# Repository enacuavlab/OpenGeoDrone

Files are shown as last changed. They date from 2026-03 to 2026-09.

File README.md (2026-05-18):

# OpenGeoDrone — Parametric RC VTOL Generator

> A fully parametric VTOL designed in OpenSCAD, built for **vase mode 3D printing**. The project generates a complete aircraft: wings with internal structure, a Bézier-profiled fuselage, motor arms, winglets, ailerons, and a center body.

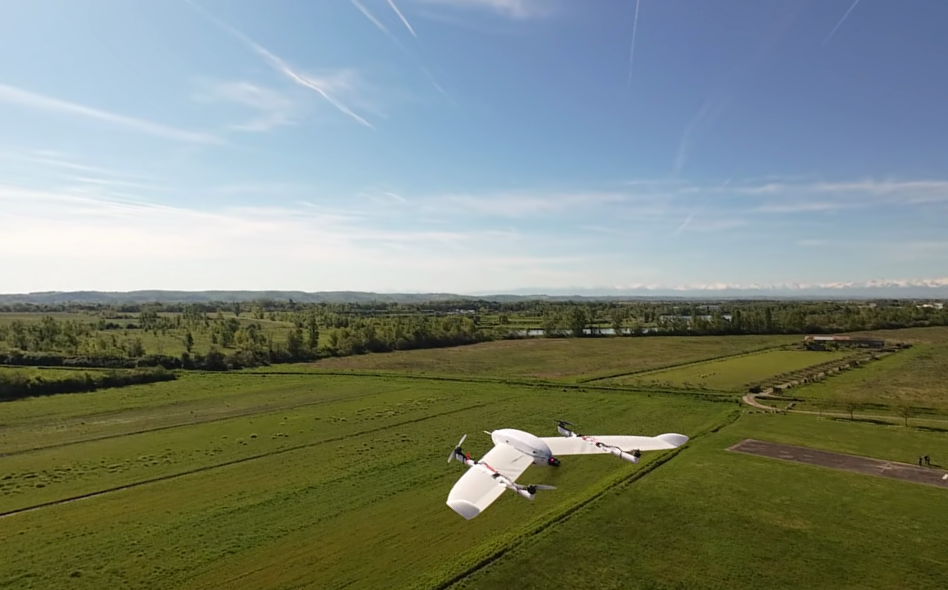
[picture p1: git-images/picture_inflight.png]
OpenGeoDrone_inflight


---

## Financial Support

The development of the OpenGeoDrone was funded by the French National Research Agency (ANR, Agence Nationale de la Recherche) and the German Research Foundation (DFG, Deutsche Forschungsgemeinschaft) within the framework of the Franco-German research project FlyHigh (ANR FlyHigh ANR-24-CE92-0015  and GR 5407/2-1)

Logo_German_Research_Foundation 
ANR

---

## Table of Contents

- [Overview](#overview)
- [Repository Structure](#repository-structure)
- [Print Tutorial](#print-tutorial)
- [OpenSCAD Quick Start](#openscad-quick-start)
- [How the Wings Are Built — The Vase Mode Method](#how-the-wings-are-built--the-vase-mode-method)
- [How the Fuselage Is Built — C1 Quintic Bézier](#how-the-fuselage-is-built--c1-quintic-bézier)
- [Parts to Print](#parts-to-print)
- [Key Parameters Reference](#key-parameters-reference)
- [Slicer Setup](#slicer-setup)
- [Performance Tips](#performance-tips)
- [Credits and Prior Work](#credits-and-prior-work)
- [License](#license)

---

## Overview

OpenGeoDrone is a VTOL UAV designed entirely in OpenSCAD. The goal is to produce aerodynamically efficient, lightweight, and printable parts using the **spiral vase mode** of FDM slicers (also called "spiralize outer contour"). This mode prints the outer skin as a single continuous spiral — no retractions, no seams, very low weight.

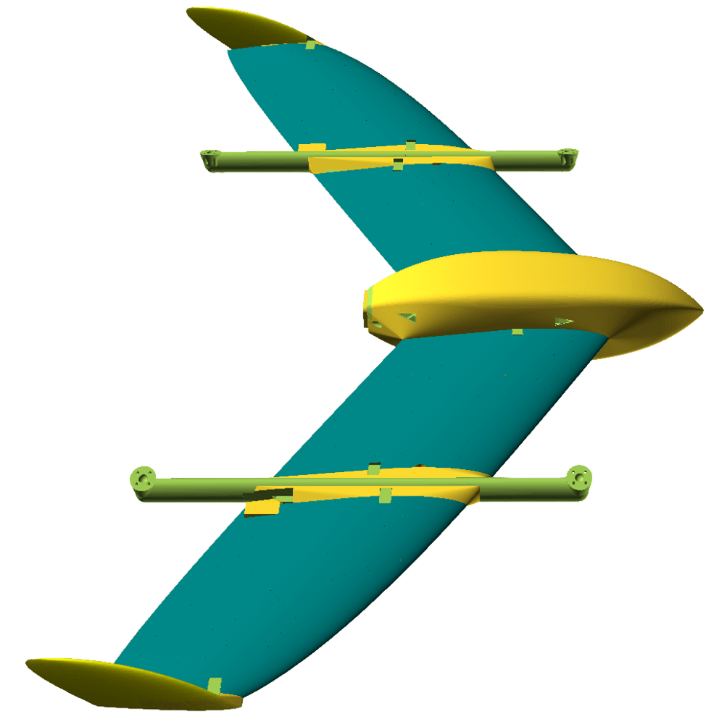
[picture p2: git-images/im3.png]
OpenGeoDrone


The aircraft is parametric end-to-end: wing span, chord, sweep, airfoil, motor position, spar count, aileron geometry, fuselage shape, and more are all driven by variables in a single file (`OpenGeoDrone.scad`). Changing one number regenerates every dependent part automatically.

**VTOL, Vertical Take-Off and Landing :**

The aircraft takes off and lands using its four hovering motors. It flies like a plane thanks to a pusher motor and two elevons.

OpenGeoDrone_inflight OpenGeoDrone_inflight

**Default aircraft specs (all configurable):**

| Specification | Value | 
|---|---|
| **Half-wingspan** | 510 mm (total ~1200 mm + center body) | 
| **Mass without battery** | 1.066kg |
| **Max payload mass** | 1.15kg with 60% throttle in hovering |
| **Flight endurance** | 25min in plane mode with 90s Hovering with 4S 4Ah battery |
| **Min plane flying speed** | 14m/s |
| **Hoovering** | 34% throttle |
| **Root chord** | 210 mm |
| **Airfoil ** | MH61 (cambered, suitable for slow stable RC flight) |
| **carbon fiber spars** | 5 (2 per half-wing + 1) |
| **Motors** | 4 hovering motors on tilted arms + one rear pusher |
| **Elevons** | 2 for pitch and roll control |
| **Center part dimensions** | 275mmx90mm  |
| **Wings easy to remove** | no cables |
| **Inertial Matrix** | coming soon |
| **Hovering power with 4S** | 400W |
| **Plane power with 4S** | 90W |

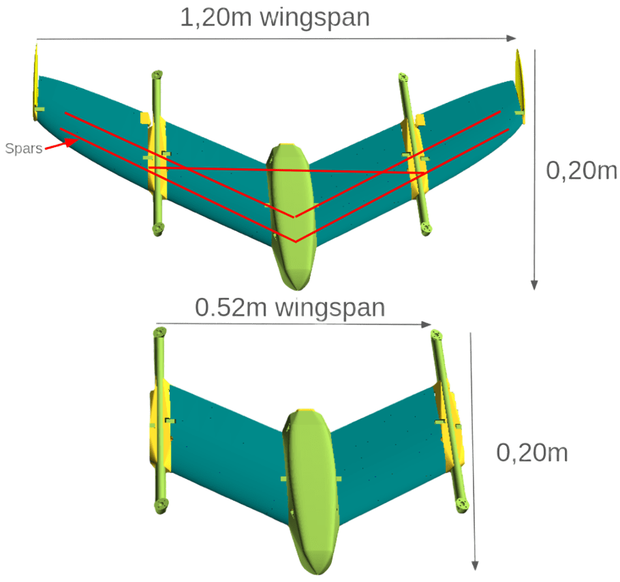
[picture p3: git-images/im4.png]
Parameters Overview


**Differents parts:**

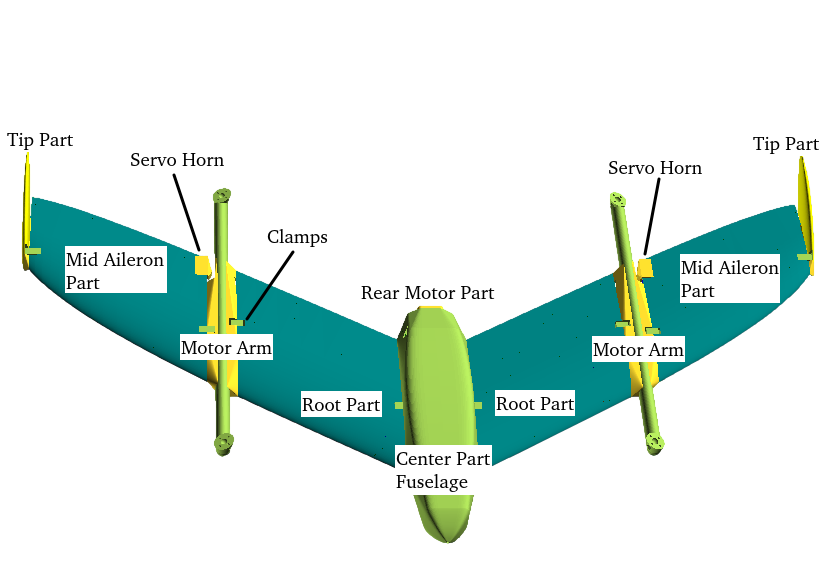
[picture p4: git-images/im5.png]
Parts Overview


---

## Print Tutorial

Every parts of the plane are printable. STL files are accessible in `stl_print_part` directory and the bambulab preset for X1C and H2D are available in `bambulab_preset` directory. It is also possible to print directly the project with the 3mf format in the `3mf_print_part` directory.

Use a **0.4mm nozzle** for all prints.

### 1st Method : 3mf format print method

It will load automatically the Bambulab preset on H2D or X1C.You can find this files in the folder `3mf_print_part`

**For X1C or H2D** : 

Use PLA Aero for :

- X1C_Left_Root_part
- X1C_Left_Mid_Aileron_part
- X1C_Right_Root_part
- X1C_Right_Mid_Aileron_part

Use PETG Basic for :

- X1C_Motor_Arms_and_sides
- X1C_Fuselage_and_Clamps
- X1C_Center_part

You choose of course the part corresponding to your printer.

### 2nd Method : STL format print method

For PLA Aero Wings, use the `0.20mm_Standard-PLA_Aero_VaseMode_XXX.json` upon your printer and print the following parts.

**PLA Aero Wings** :

- Left_Root_part
- Right_Root_part
- Left_Mid_Aileron_part
- Right_Mid_Aileron_part

For Side parts, Clamps parts and Center body below, you can print it in PETG Basic in standard mode (0.20mm Standard)

**Side parts** :

- Left_Motor_arm_back
- Left_Motor_arm_front
- Right_Motor_arm_back
- Right_Motor_arm_front
- Left_Servo_horn
- Right_Servo_horn

**Clamps parts** :

- 6 x Clamp_fixation_big

**Center body** :

- Center_part
- Fuselage_bottom_back_part
- Fuselage_front_part
- Fuselage_upper_part
- Rear_motor_part

### Hardware (not printed)

- Carbon fiber tube ⌀5.5 mm
- Carbon fiber tube ⌀6.5 mm
- Flight controller (e.g. Tawaki)
- 2 Servo
- RC
- Pitot tube
- GPS module and Modem to Ground station if needed
- 4 Motors for hoovering (F40) 
- 1 ESC 4 to 1 
- 2 Propellers 7x4 and 2 reverse Propellers 7x4  
- 1 Motor for pusher (low kV < 1200) 
- 1 ESC for pusher 
- 1 Propeller 9x6

### Assembly order

1. **TODO**

---

## Repository Structure

```
Vase_wing_openscad/
│
├── OpenGeoDrone.scad               # Main entry point — all parameters and top-level assembly
│
├── lib/
│   ├── Wing-Creator.scad      # Wing shell geometry (airfoil lofting, sweep, washout)
│   ├── Grid-Structure.scad    # Internal rib and spar grid structure
│   ├── Grid-Void-Creator.scad # Clearance voids ensuring vase mode continuity
│   ├── Rib-Void-Creator.scad  # Optional weight-reduction holes in ribs
│   ├── Spar-Hole.scad         # Carbon spar tube holes and retaining rings
│   ├── Aileron-Creator.scad   # Aileron geometry, pin holes, command pin voids
│   ├── Motor-arm.scad         # Motor arm tube, tilt, attachment to wing
│   ├── Winglet-Creator.scad   # Winglet geometry and attachment interface
│   ├── Center-part.scad       # Center body / fuselage assembly
│   ├── Servo-Hole.scad        # Servo pocket geometry
│   ├── Helpers.scad           # Utility functions (chord interpolation, spline, etc.)
│   ├── Tools.scad             # General geometry helpers
│   └── openscad-airfoil/      # Airfoil coordinate libraries (MH45, NACA0008, etc.)
│
├── bambulab_preset/           # Ready-to-import slicer presets for Bambu Lab printers
├── git-images/                # Screenshots of rendered wings for this README
├── stl_generator.sh           # Bash script to batch-export all STL files via OpenSCAD CLI
└── README.md                  # This file
```

**The single file to open is `OpenGeoDrone.scad`.** All parameters live at the top of that file. The `lib/` modules are included automatically — you never need to edit them directly.

---

## OpenSCAD Quick Start

### 1. Install OpenSCAD with the Manifold engine

Standard OpenSCAD is very slow on this model. Use the **development snapshot** with the Manifold geometry engine, which is approximately 100× faster:

1. Download a development snapshot: [openscad.org/downloads.html#snapshots](https://openscad.org/downloads.html#snapshots)
2. Open **Edit → Preferences → Features**
3. Enable the **Manifold** checkbox

### 2. Open the project

```
File → Open → OpenGeoDrone.scad
```

### 3. Select the part to render

At the top of `OpenGeoDrone.scad`, set exactly one part flag to `true`:

```openscad
// --- Choose the part to export ---
Root_part                 = true;   // Wing root section (fuselage side)
Mid_Aileron_part          = false;  // Mid section + aileron as one piece
Tip_part                  = false;  // Wing tip section (+ winglet if enabled)
Motor_arm_full            = false;  // Motor arm (front + back together)
Motor_arm_front           = false;  // Front half of motor arm only
Motor_arm_back            = false;  // Rear half of motor arm only
Servo_horn                = false;  // Servo horn

Center_part               = false;  // Center body / fuselage
Rear_motor_part           = false;  //Part for Rear motor attach
Clamp_fixation_big        = false;  // Clamp to fix parts together (ie wings to center_part or motor_arm)
Clamp_fixation_small      = false;  // Clamp to fix parts together (ie wing_tips to center_part or motor_arm)
Fuselage_front_part       = false; // Fuselage
Fuselage_bottom_back_part = false; // Fuselage
Fuselage_upper_part       = false; // Fuselage
Full_fuselage             = false; // Fuselage parts all together

Full_system        = false;  // Full assembly preview (not for printing)

// --- Choose the side ---
Left_side  = true;   // Generate left wing half
Right_side = false;  // Generate right wing half (mirrored)
```

### 4. Render and export

Press **F6** to render, then **File → Export → Export as STL**.

To export as STL all parts at once, use the batch script:

```bash
./stl_generator.sh
```

Parts will be exported in folder **stl_output**

---

## How the Wings Are Built — The Vase Mode Method

### What is vase mode?

Vase mode (also called "spiralize outer contour") is a slicer setting that prints only the outer wall as a single continuous upward spiral — no infill, no top/bottom layers, no retractions. For a wing this is ideal: the airfoil skin becomes a single-layer seamless tube that is light, smooth, and aerodynamically clean.

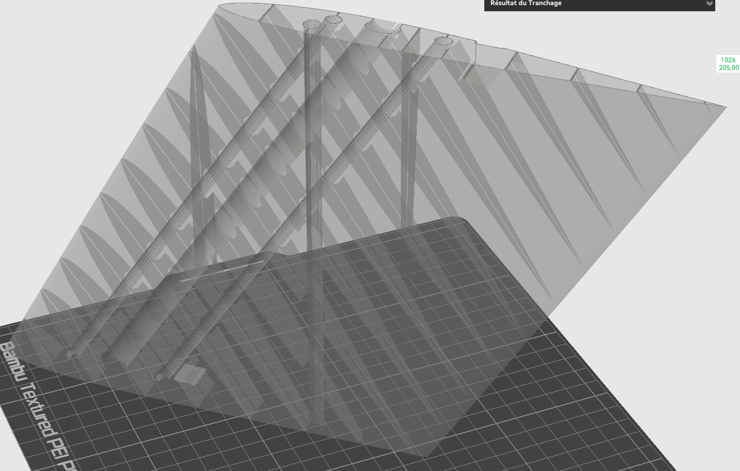
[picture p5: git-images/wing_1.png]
Print Wing


The geometry must be designed specifically for this mode. At every layer height, the cross-section of the model must form a **single closed contour** — if the slicer sees multiple disconnected loops, it cannot maintain the spiral and the print fails. Every design decision in this project (grid voids, spar hole placement, aileron connection geometry) exists to satisfy this constraint.

Print Wing

### Step 1 — Airfoil cross-sections

The wing shape starts with a 2D airfoil polygon. OpenGeoDrone uses profiles from the [openscad-airfoil](https://github.com/guillaumef/openscad-airfoil) library, which stores airfoil coordinates as OpenSCAD path arrays. These were pre-processed from UIUC `.dat` files using AeroSandbox to increase point density, resulting in smoother printed curves.

The default airfoil is **MH61**, a cambered profile well-suited for slow stable RC flight. The winglet uses **NACA0008**, a symmetric thin profile. Up to three different airfoils can be blended along the span (root, mid, tip) using `slice_transitions`.

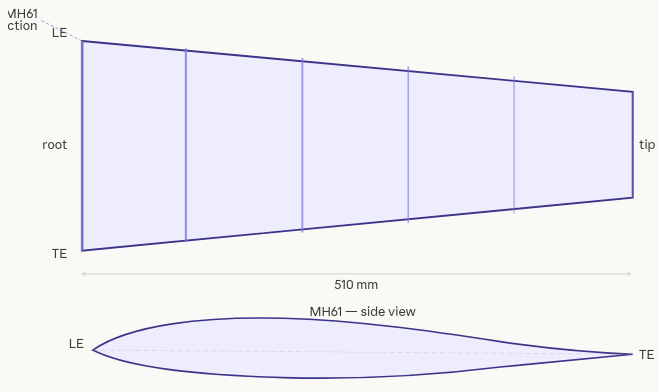
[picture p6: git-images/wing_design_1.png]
Create profile and rescale


### Step 2 — Wing shell lofting

The wing outer skin is generated by `CreateWing()` in `Wing-Creator.scad`. The airfoil cross-section is placed and transformed at `wing_sections` spanwise stations (default: 50). At each station `z`, the section is:

- **Scaled** to the local chord length, following either a trapezoidal or elliptic planform (`wing_mode` parameter)
- **Swept** in X by a user-defined spline (`lead_edge_sweep` parameter) — this shifts the leading edge rearward as span increases, giving the wing its arrow shape
- **Curved** in Y by an optional spline (`lead_edge_curve_y`) — used for dihedral
- **Washed out** by rotating the section about a pivot point (`washout_pivot_perc` parameter) to progressively reduce angle of attack toward the tip, which improves stall behavior

The elliptic chord distribution uses a super-ellipse formula:

```
chord(z) = root_chord × (1 − (z / span)^p)^(1/p)
```

where `p = elliptic_param`. 

- A value of 2 gives a true ellipse 
- Values > 2 give a squarer tip 
- Values < 2 give a sharper tip

Apply transformation Elliptic wing, sweep, curve, washout, etc …

Each station is a near-zero-thickness extruded polygon. OpenSCAD's `hull()` operation connects consecutive stations into a smooth lofted surface — the wing outer skin.

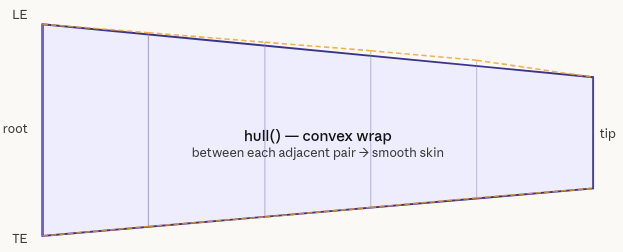
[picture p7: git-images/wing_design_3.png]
Connect all section together


### Step 3 — Internal grid structure

The wing skin alone is too flexible. An internal rib-and-spar grid is built by `Grid-Structure.scad` and subtracted from the wing volume, creating a periodic internal skeleton visible through the skin after printing.

Two grid modes are available:

**Mode 1 — Diamond grid:** A diagonal lattice scaled by `grid_size_factor`. Lightweight and uniform, but without defined spar paths.

**Mode 2 — Spar + cross-rib grid (default):** Longitudinal spar walls at the same chord percentages as the carbon tubes, connected by `rib_num` transverse ribs. This is a structurally coherent option — the grid walls and the tube channels form a unified load path.

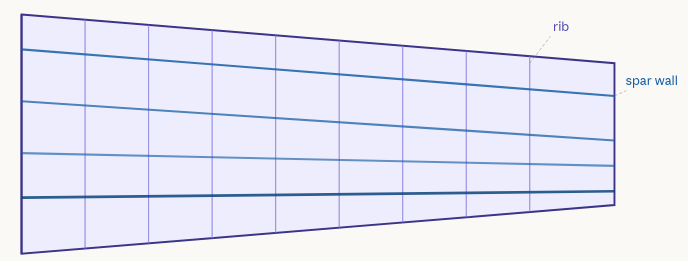
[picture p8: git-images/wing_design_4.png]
Internal grid structure and spars


After the grid is built, `CreateGridVoid()` cuts narrow channels along every grid wall. **This is the key to vase mode compatibility**: the channels reduce each internal wall to a thin fin rather than a solid block, ensuring the slicer always sees a single outermost contour at every layer.

Keypoints cuts narrow channels along every grid wall

### Step 4 — Carbon spar holes

Three carbon fiber tube channels are cut through the wing by `Spar-Hole.scad`:

| Spar | Position from leading edge | Tube diameter |
|---|---|---|
| Spar 1 | 15% of chord | 5.5 mm |
| Spar 2 | 37% of chord | 5.5 mm |
| Spar 3 | 75% of chord | 6.5 mm |

Spar 1 and 2 holes are angled to follow the leading edge sweep, so the carbon tube runs geometrically parallel to the wing planform. Spar 3 is perpendicular to the root face and bigger diameter to increase the structure rigidity and create a block mechanism with a triangle system.

Around each hole, a ring of 12 small retaining circles (`spar_circle_holder = 0.25 mm`) creates a snap-fit friction interface that holds the tube in place after insertion without glue.

The same holes continue into the center body to connect both wing halves through the fuselage.

OpenSCAD prints the required tube lengths to the console at render time:

```
[SPAR] Spar 1 at 15% from LE is XXX mm length.
[SPAR] Spar 2 at 37% from LE is XXX mm length.
[SPAR] Spar 3 at 75% from LE is XXX mm length.
```

**Cut your carbon tubes to these exact lengths before assembly.**

### Step 5 — Elevons

Elevons are sticked to the mid part :
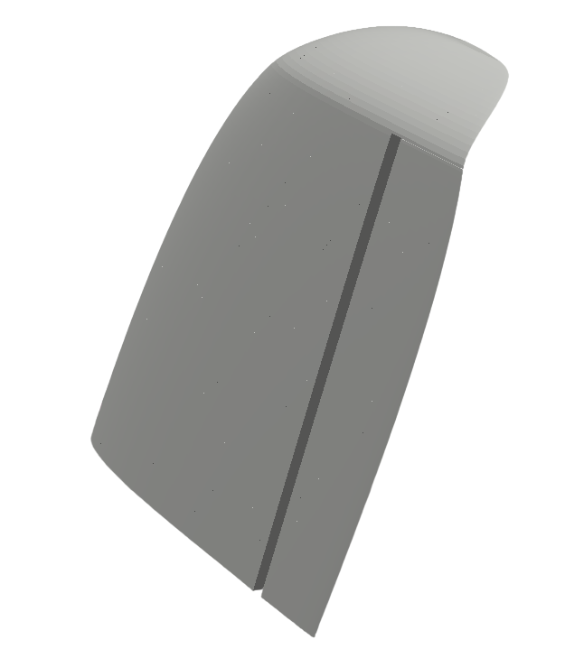
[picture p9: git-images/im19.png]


The connection between the mid part and the aileron is performed by a thin layer and tht actuation is done by the servo horn part connected to your servo:

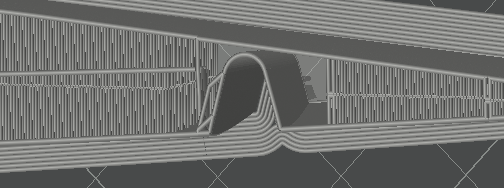
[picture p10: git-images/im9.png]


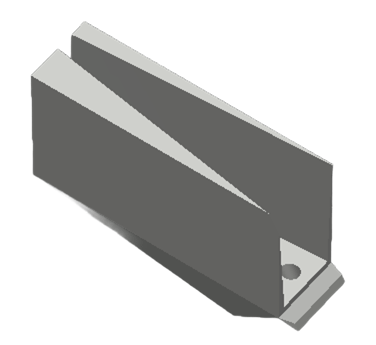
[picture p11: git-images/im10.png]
Servo Horn Part


### Step 6 — Clamp

Clamp are used to hold parts together, insert them slowly into the 6 places :

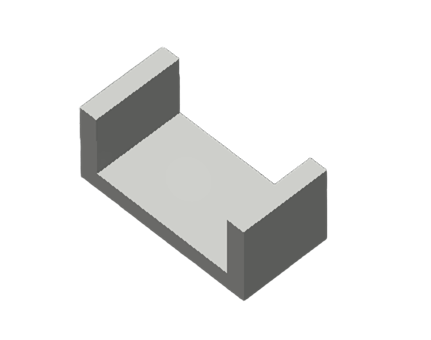
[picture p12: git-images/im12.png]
Clamp_fixation Part


---

## How the Fuselage Is Built — C1 Quintic Bézier

The fuselage / center body profile is defined by a **quintic Bézier curve** (degree 5, 6 control points) that describes the body radius along the longitudinal axis. This gives a smooth, aerodynamic shape with guaranteed C1 continuity at both endpoints — the tangent is well-defined at the nose and tail, preventing any abrupt transitions.

### Longitudinal profile

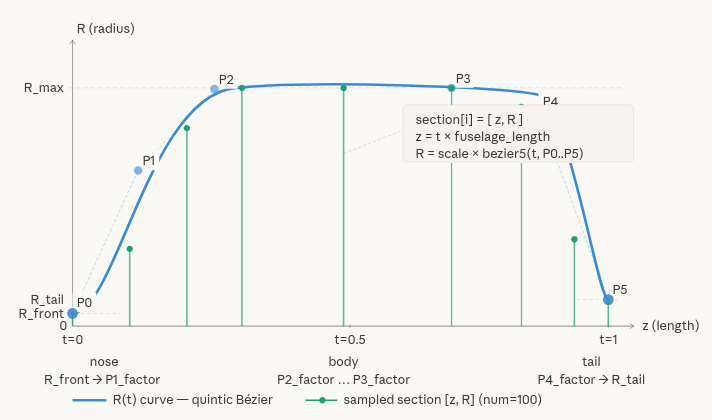
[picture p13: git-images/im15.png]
Bezier curve fuselage Part


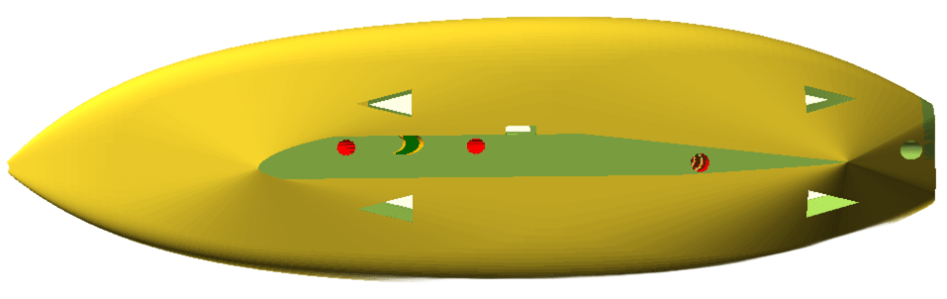
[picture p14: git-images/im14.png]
fuselage Part


The six control points are derived from three base radii and five shape factors:

| Point | Value | Role |
|---|---|---|
| P0 | `R_front` | Nose radius |
| P1 | `R_front + P1_factor × (R_max − R_front)` | Nose tangent — controls C1 smoothness at nose |
| P2 | `R_front + P2_factor × (R_max − R_front)` | Controls widening speed |
| P3 | `R_tail + P3_factor × (R_max − R_tail)` | Controls how long the body stays wide |
| P4 | `R_tail + P4_factor × (R_max − R_tail)` | Tail tangent — controls C1 smoothness at tail |
| P5 | `R_tail + P5_factor × (R_max − R_tail)` | Tail radius |

The curve is numerically normalized so that `max(R(t))` is equal to center_part width, regardless of what factor values are chosen.

### Cross-section — asymmetric super-ellipse

Each longitudinal station generates a 2D polygon using an **asymmetric super-ellipse**:

```
ca = cos(a),  sa = sin(a)

x = rx · sign(ca) · |ca|^(2/nx)
y = ry · sign(sa) · |sa|^(2/ny)
```

The vertical radius `ry` uses two independent scaling factors:

- **Upper half** (`sa ≥ 0`): `ry = rx × fuselage_scale_y_top`
- **Lower half** (`sa < 0`): `ry = rx × fuselage_scale_y_bottom`

This makes the fuselage asymmetric vertically — for example, flatter on the bottom for a landing skid while remaining more rounded on top. Both halves meet seamlessly at `y = 0`.

The exponents in `fuselage_ellipse_param = [nx, ny]` control the cross-section shape:
- `n = 2` → standard ellipse
- `n = 4` → rounded rectangle
- `n → ∞` → rectangle

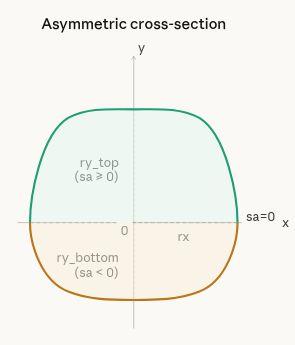
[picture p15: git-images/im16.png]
Cross-section


### Assembly

`fuselage_sections()` produces an array of 101 pairs `[z, rx]` by evaluating the Bézier curve at `num = 100` equally spaced parameter values. Each pair becomes one frame — a thin 2D polygon at position `z` along the body axis.

The fuselage is then assembled in by chaining `hull()` between every pair of consecutive frames, producing 100 smooth segments that form a seamless body skin.

Finally, the module wraps the fuselage in a global `hull()` together with the inboard wing root cross-sections, creating a smooth aerodynamic fairing between fuselage and wing with no sharp steps or manual fillets.

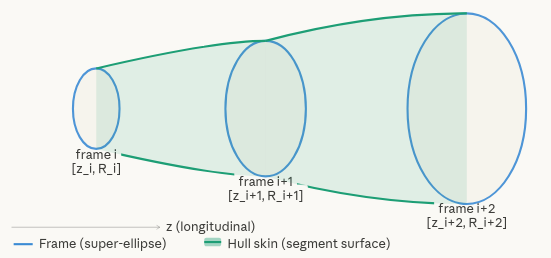
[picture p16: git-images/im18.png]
Assembly


---

## Key Parameters Reference

### Wing geometry

| Parameter | Default | Description |
|---|---|---|
| `wing_mm` | 500 | Half-wingspan in mm |
| `wing_root_chord_mm` | 180 | Root chord length in mm |
| `wing_tip_chord_mm` | 110 | Tip chord (trapezoidal mode only) |
| `wing_mode` | 2 | `1` = trapezoidal, `2` = elliptic |
| `elliptic_param` | 3.5 | Elliptic exponent (2 = true ellipse, >2 = squarer tip) |
| `wing_sections` | 50 | Spanwise resolution — higher = smoother, slower |
| `wing_root_mm` | 215 | Spanwise length of root section |
| `wing_mid_mm` | 245 | Spanwise length of mid section |
| `AC_CG_margin` | 10% | CG target margin aft of aerodynamic center |

### Fuselage

| Parameter | Default | Description |
|---|---|---|
| `center_width` | 80 mm | Maximum fuselage width |
| `center_length` | 275 mm | Fuselage total length |
| `R_front` | 1 mm | Nose radius |
| `R_max` | `center_width/2` | Maximum body radius (normalized exactly) |
| `R_tail` | 5 mm | Tail exit radius |
| `fuselage_scale_y_top` | 1.2 | Upper half vertical scaling ratio |
| `fuselage_scale_y_bottom` | 1 | Lower half vertical scaling ratio |
| `fuselage_ellipse_param` | `[7, 4.8]` | Cross-section super-ellipse exponents `[nx, ny]` |
| `num` | 100 | Number of longitudinal Bézier frames |

### Carbon spars

| Parameter | Default | Description |
|---|---|---|
| `spar_hole_perc` | 15% | Spar 1 chord position from leading edge |
| `spar_hole_perc_2` | 37% | Spar 2 chord position |
| `spar_hole_perc_3` | 75% | Spar 3 chord position |
| `spar_hole_size` | 5.6 mm | Spar 1 & 2 tube outer diameter |
| `spar_hole_size_3` | 6.65 mm | Spar 3 tube outer diameter |
| `spar_circles_nb` | 12 | Retaining ring segment count |
| `spar_circle_holder` | 0.25 mm | Retaining ring interference radius |

### Motor arm

| Parameter | Default | Description |
|---|---|---|
| `motor_arm_length_front` | 170 mm | Front tube length |
| `motor_arm_length_back` | 210 mm | Rear tube length |
| `motor_arm_tilt_angle` | 20° | Motor tilt angle |
| `motor_arm_height` | 19 mm | Arm cross-section height |
| `ellipse_maj_ax` | 9 mm | Arm tube major axis radius |
| `ellipse_min_ax` | 13 mm | Arm tube minor axis radius |

### Quality and rendering

| Parameter | Default | Description |
|---|---|---|
| `draft_quality` | `false` | Set to `true` for fast coarse preview |
| `$fa` | 5° | Maximum angle between mesh segments |
| `$fs` | 1 mm | Maximum segment length |

---

## Slicer Setup

### Vase mode settings (all slicers)

**TODO**

### Bambu Lab

Import the presets from the `bambulab_preset/` folder. If the import fails, check that the preset version matches your printer firmware and update the version field in the JSON if needed.

Known issue: Bambu Studio can crash when slicing large models due to an NVIDIA driver conflict. See [this forum thread](https://forum.bambulab.com/t/bambu-studio-crashes-after-slicing-solved-nvidia-problem/162392) for the fix.

### Material

- **PLA Aero** : for wings
- **PETG** : for all other parts

---

## Performance Tips

**Render is very slow:**
- Enable the **Manifold** engine in OpenSCAD preferences
- Set `draft_quality = true` for a fast preview pass
- Lower `wing_sections` if you see the warning: `"Normalized tree is growing past 200000 elements. Aborting normalization."`

**Spar hole not appearing in the model:**
- The spar hole is too far from any skin edge — the vase circuit connection path is too long for the slicer to close
- Toggle `spar_flip_side_1`, `spar_flip_side_2`, or `spar_flip_side_3` to route the connection toward the nearest edge instead

**Aileron binds or is too tight after printing:**
- Increase `y_offset_aileron_to_wing` slightly (try 0.8–1.0 mm)
- Adjust `ailerons_pin_hole_dilatation_offset_PLA` (increase slightly if pin is too tight)

**Adding custom inserts inside the wing:**
- Always cut a clearance void around any added component before subtracting it from the wing
- Without the void, the insert will conflict with adjacent rib walls and break the vase contour

---

## Credits and Prior Work

This project builds on and extends the following open-source work:

- **[Beachless/Vase-Wing](https://github.com/Beachless/Vase-Wing)** — the original vase mode wing generator for OpenSCAD that directly inspired this project
- **[BouncyMonkey — Propeller Generator](https://www.thingiverse.com/thing:3506692)** — wing lofting and construction technique adapted here
- **[guillaumef/openscad-airfoil](https://github.com/guillaumef/openscad-airfoil)** — Perl script and SCAD library for converting airfoil `.dat` files into OpenSCAD polygon paths
- **[peterdsharpe/AeroSandbox](https://github.com/peterdsharpe/AeroSandbox)** — used to resample airfoil coordinate files to higher density for smoother printed curves
- **[UIUC Airfoil Database](http://m-selig.ae.illinois.edu/ads/coord_database.html)** — source of MH61 and NACA airfoil coordinate data

---

## License

GPL-3.0 — see [LICENSE](LICENSE) for details.

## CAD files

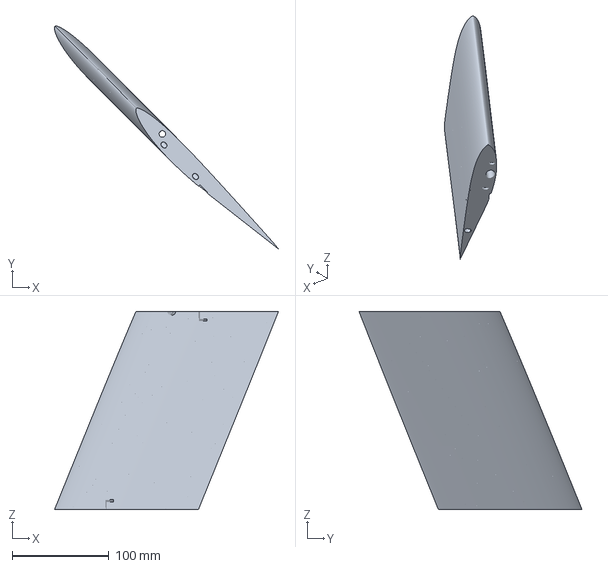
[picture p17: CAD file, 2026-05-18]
3mf_print_part/H2D_Right_Root_part.3mf
231.8 x 230.9 x 205.0 mm

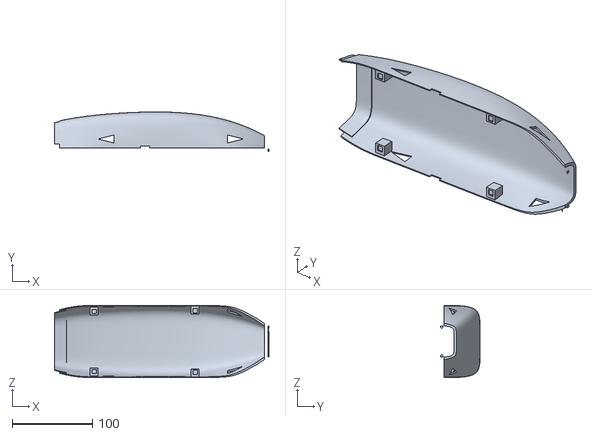
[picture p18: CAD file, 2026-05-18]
stl_print_part/Fuselage_upper_part.stl
266.8 x 56.2 x 90.0

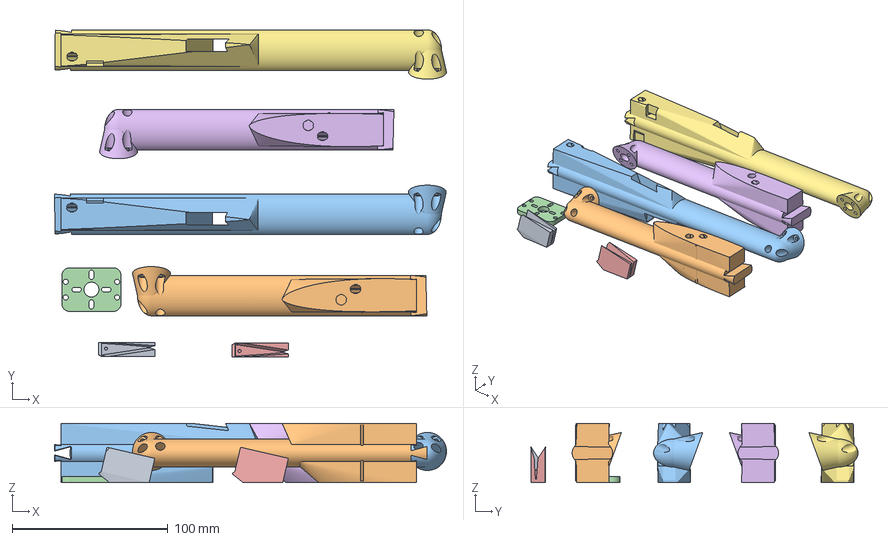
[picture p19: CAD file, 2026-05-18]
3mf_print_part/X1C_Motor_Arms_and_sides.3mf
251.4 x 209.9 x 38.0 mm
Right_Servo_horn.stl
Right_Motor_arm_front.stl
Right_Motor_arm_back.stl
Rear_motor_part.stl
Left_Servo_horn.stl
Left_Motor_arm_front.stl
Left_Motor_arm_back.stl

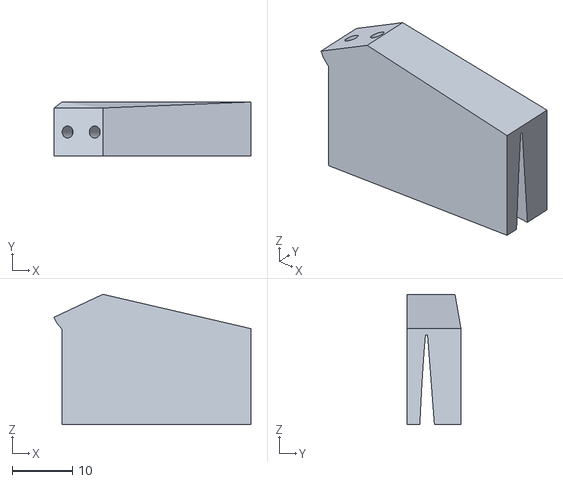
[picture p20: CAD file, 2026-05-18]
stl_print_part/Right_Servo_horn.stl
32.8 x 9.00 x 21.7

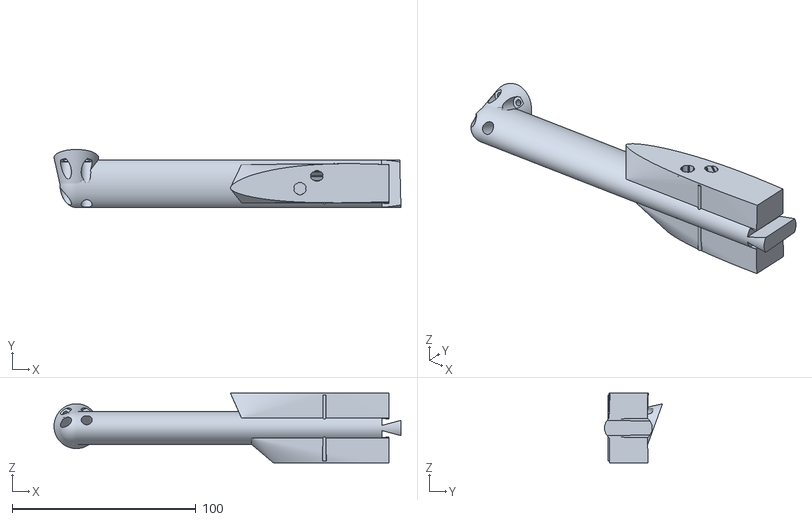
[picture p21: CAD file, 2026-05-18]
stl_print_part/Right_Motor_arm_front.stl
188.8 x 31.6 x 38.0

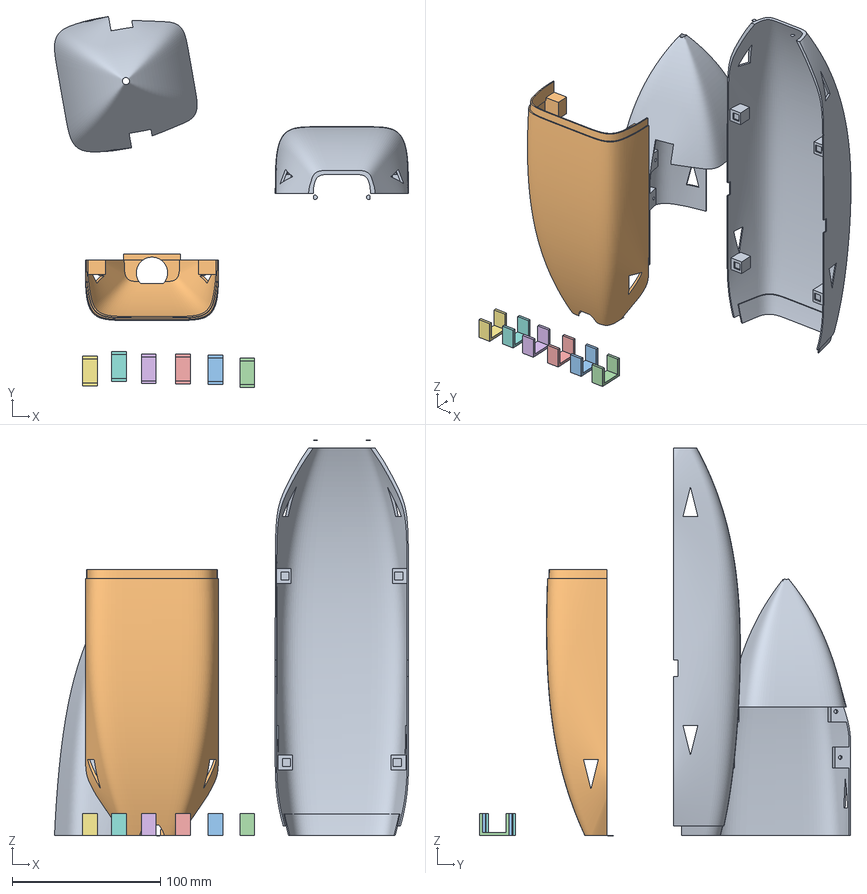
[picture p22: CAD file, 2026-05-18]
3mf_print_part/H2D_Fuselage_and_Clamps.3mf
239.1 x 250.6 x 266.8 mm
Fuselage_front_part.stl
Fuselage_bottom_back_part.stl
Clamp_fixation_big.stl x 6
Fuselage_upper_part.stl

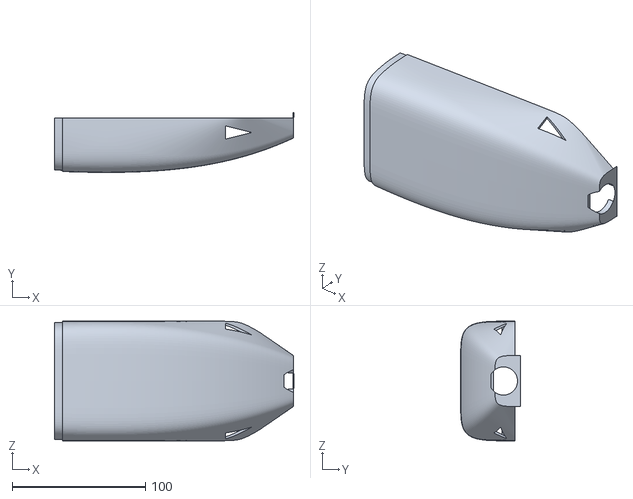
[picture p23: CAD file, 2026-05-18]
stl_print_part/Fuselage_bottom_back_part.stl
179.6 x 45.0 x 90.0

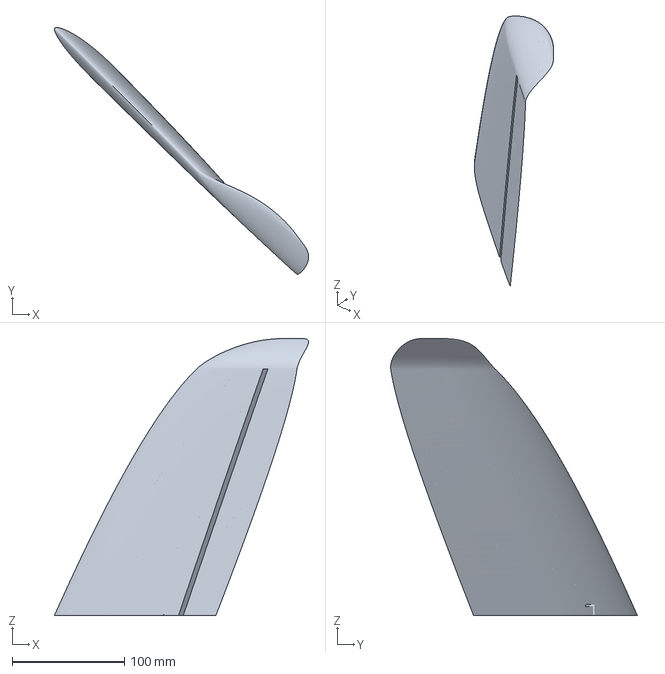
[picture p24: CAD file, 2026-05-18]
3mf_print_part/H2D_Left_Mid_Aileron_part.3mf
226.7 x 220.0 x 247.0 mm

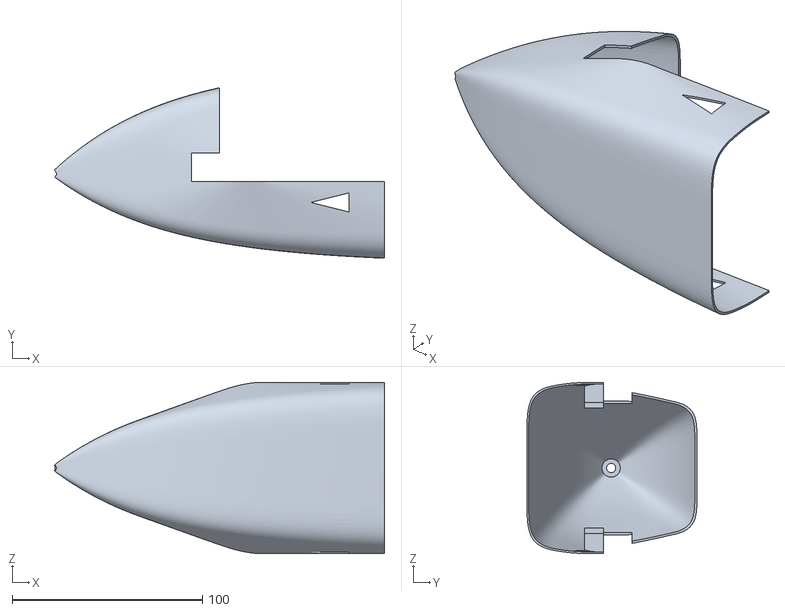
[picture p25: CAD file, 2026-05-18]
stl_print_part/Fuselage_front_part.stl
173.3 x 89.5 x 90.0

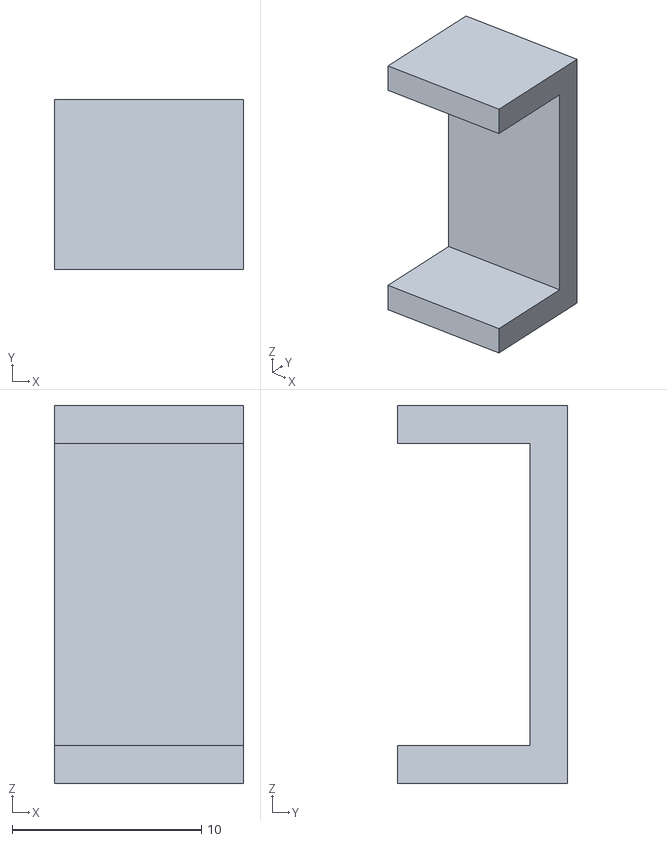
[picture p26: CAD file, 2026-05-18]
stl_print_part/Clamp_fixation_small.stl
10.0 x 9.00 x 20.0

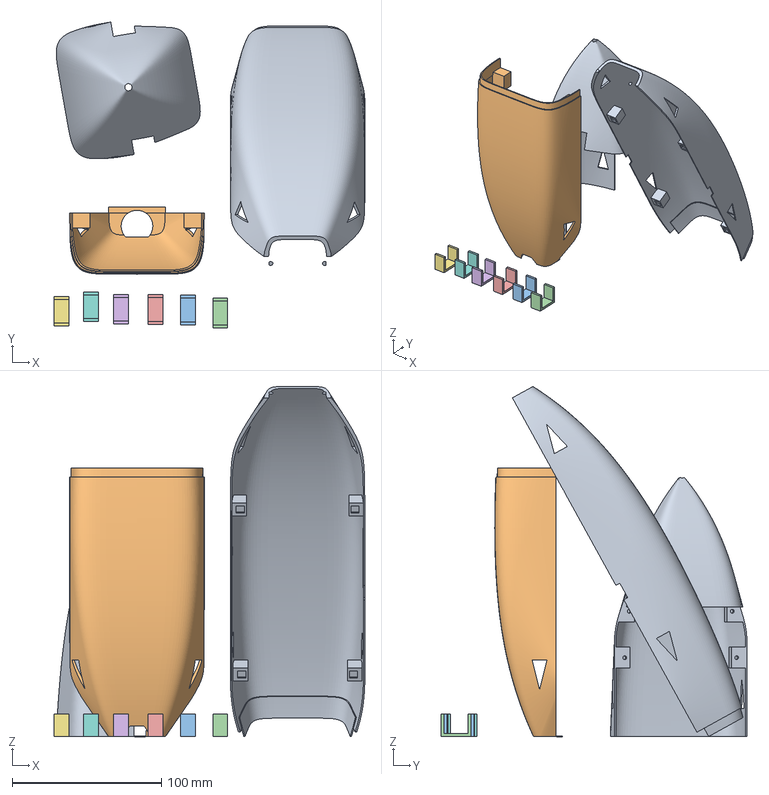
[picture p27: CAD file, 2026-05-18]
3mf_print_part/X1C_Fuselage_and_Clamps.3mf
207.9 x 204.7 x 234.2 mm
Fuselage_front_part.stl
Fuselage_bottom_back_part.stl
Clamp_fixation_big.stl x 6
Fuselage_upper_part.stl

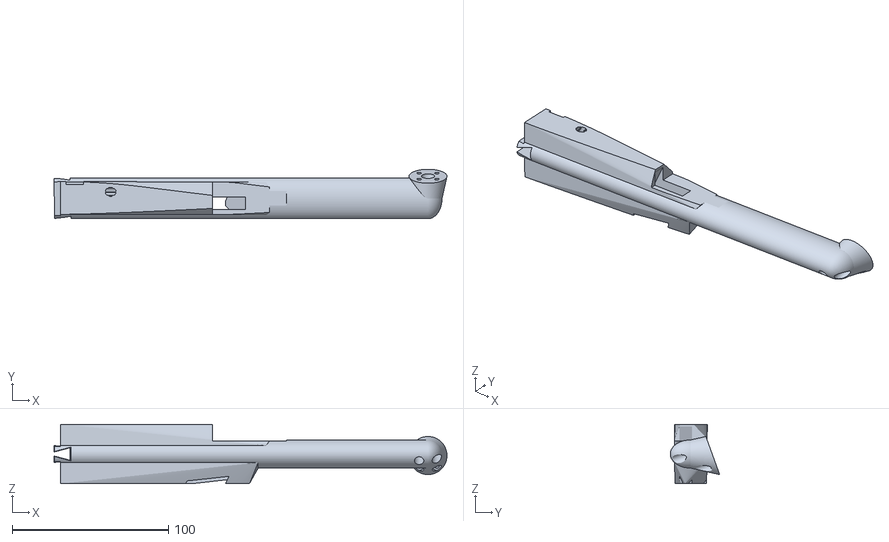
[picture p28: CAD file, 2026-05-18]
stl_print_part/Left_Motor_arm_back.stl
251.2 x 31.6 x 38.0

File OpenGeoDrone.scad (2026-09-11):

// RC wing generator for Vase mode printing
//
// Prior work used to create this script:
// https://www.thingiverse.com/thing:3506692
// https://github.com/guillaumef/openscad-airfoil
 
//Tips
// 1- If you want to add something into the wing, add a void offset around the part you want to add to avoid conflict with intern ribs during vase print  
// 2- When spar hole is far from a edge and the vase circuit connection is too long, the system doesnt like and don't draw the spar hole. Use spar_flip_side parameter to orientate the vase circuit connection to the closest edge
// 3- if you get this error : "WARNING: Normalized tree is growing past 200000 elements. Aborting normalization." -> decrease the wing_sections value
// 4 - Setting you might need to play with : in connection_mid_to_ailerons, there is two offsets to set the  connection as close as possible to the wall. You can play with them in case it's too close to the wall (hole) or too far


// Note Printer 
// 1- No support in motor arm spar holes
// 2- use PLA Aero user preset to get nice print
// 3- Bambulab can crash each time you enter a too large model to slice. It can be due to a NVIDIA parameter for bambulab, here is the solution : https://forum.bambulab.com/t/bambu-studio-crashes-after-slicing-solved-nvidia-problem/162392
// 4- When you import a preset, the import can not work due to version difference. Be carefull to update the version of your printer into the preset document you want to import





// Wing airfoils
include <lib/openscad-airfoil/m/mh61.scad>
include <lib/openscad-airfoil/n/naca0008.scad>
af_vec_path_root =             airfoil_MH61_path();
af_vec_path_mid  =             airfoil_MH61_path();
af_vec_path_tip  =             airfoil_MH61_path();
module RootAirfoilPolygon() {  airfoil_MH61();  }
module MidAirfoilPolygon()  {  airfoil_MH61();  }
module TipAirfoilPolygon()  {  airfoil_MH61();  }

//Profil use for winglet => symetric
module wingletAirfoilPolygon() {  airfoil_NACA0008();  }




// TODO
// Readme : pictures update
// Readme : Center of gravity before flying + check pitot etc
// Readme : Where put payload
// Readme : Inertial matrix
// increase section only in wingtip NOK
// reduce mass center part 
// ASA test Fuselage
// Winggenerator





//Later :
// Arm + center + fuselage => angle pitch comp
// Rear motor pitch or not ?
// Clean too much param
// Ailerons module clean
// Try on Orca and add printer conf in git
// Note on openscad nightly and manifold option
// Optimize wing grid and hole vs mass
// NVL implementation

//*******************END***************************//

//****************Global Variables*****************//

// Printing Mode : Choose which part of wings you want
Full_system = true;

Left_side = true;
Right_side = false;

// Choose one at a time
Root_part = false;
Mid_Aileron_part = false;
Tip_part = false;
Motor_arm_full = false;
Motor_arm_front = false;
Motor_arm_back = false;
Servo_horn = false;

Center_part = false;
Rear_motor_part = false;
Clamp_fixation_big = false;
Clamp_fixation_small = false;
Fuselage_front_part = false;
Fuselage_bottom_back_part = false;
Fuselage_upper_part = false;
Full_fuselage = false;

// No use 
Aileron_part = false;
Mid_part = false;

//**************** Quality settings **********//
draft_quality = false;
$fn = $preview ? 1 : 150;
$fa = $preview ? 20  :  1;
$fs = $preview ? 20 :  0.1;
//$fa = draft_quality?1:5; //Maximum angle between two segments. → Smaller = more segments = smoother.
//$fs = draft_quality?0.1:1; //(fragment size): maximum length of a segment.→ Smaller = shorter segments = smoother.
//wing_sections = draft_quality?1:30;
wing_sections = $preview ? 5:100; // more is higher resolution but higher processing. We decrease wing_sections for Full_system because it's too much elements just for display


 
echo(str("fn = ",$fn));
echo(str("fa = ",$fa));
echo(str("fs = ",$fs));

//****************Wing Airfoil settings**********//
wing_mm = 490;            // wing length in mm (= Half the wingspan)
wing_root_chord_mm = 210; // Root chord length in mm
wing_tip_chord_mm = 110; // wing tip chord length in mm (Not relevant for elliptic wing);
wing_center_line_perc = 70; // Percentage from the leading edge where you would like the wings center line
wing_mode = 2; // 1=trapezoidal wing 2= elliptic wing
center_airfoil_change_perc = 100; // Where you want to change to the center airfoil 100 is off
tip_airfoil_change_perc = 100;    // Where you want to change to the tip airfoil 100 is off
slice_transisions = 0; // This is the number of slices that will be a blend of airfoils when airfoil is changed 0 is off
elliptic_param = 3.5; //Parameter for surrellipse adjustement. Ellipse = 2. Square tip >2 and Sharp tip <2
pitch_trim = 0; //Parameter for global pitch trim on motor arm, fuselage, center part in degree


//**************** Motor arm **********//
ellipse_maj_ax = 8;//9;        // ellipse's major axis (rayon z)
ellipse_min_ax = 10;//13;        // ellipse's minor axis (rayon y)
motor_arm_length_front = 170;        // Tube length z
motor_arm_length_back = 235;//210;        // Tube length z
motor_arm_y_offset = 3;   //Offset on Y axis
motor_arm_height = 19;      // Height of motor arm
motor_arm_tilt_angle  = 20; // Tilt angle of motor arm
motor_arm_screw_fit_offset = 2; // Offset to adjust screw position after rotation
dummy_motor = false; // Parameters to see how the helix is positionned in comparison of the aircraft
motor_arm_grav_center_offset = 35;
motor_arm_to_wing_hull = 10; //Length of hull for transition from motor arm to wings
gravity_line_y_offset = -1; // Y offset management on motor arm
// More parameters are available inside the motor_arm module



//**************** Wing Airfoil dimensions **********//
// Total length must do wing_mm
motor_arm_width = 2*ellipse_maj_ax;
wing_root_mm = 215;
wing_mid_mm = 230;//245;
wing_tip_mm = wing_mm - wing_root_mm - wing_mid_mm - motor_arm_width;
AC_CG_margin = 10; //Margin between mean aerodynamic center and gravity center in percentage
aerodyn_center_plot = false; //Black
gravity_center_plot = false; //Green
//******//


//**************** Fuselage and center part **********//
center_width = 90; //55;
center_length = 275;
center_height = 8.5;//15;
center_part_y_offset = 0;//0;
main_stage_y_width = 1.6*center_height/3;//2.2*center_height/3;
main_stage_x_offset = center_length/10;
battery_width = center_width -21;//-10; // Distance of battery holder void from extremity
battery_hole_width = 8;
battery_hole_length = 25;
//Battery holder void place
battery_x_pos_6 = -7;
battery_x_pos_1 = 35;
battery_x_pos_7 = 99;
battery_x_pos_2 = 100;
battery_x_pos_3 = 125;
battery_x_pos_4 = 170;
battery_x_pos_5 = 186;
//Tawaki x offset on center part position
tawaki_x_offset_pos = 100;
//ESC x offset on center part position (from rear motor end)
esc_x_offset_pos = 25;
// === Center Part Grid Parameters ===
slot_width    = 1.5;//2.5;     
slot_spacing  = 20;//18;     
grid_angle    = 45;  
grid_z_offset =20;

// === Fuselage Parameters ===
nozzle_length = 100;
tail_length = 0;
fuselage_z_offset = center_width/2;
L_total = center_length - main_stage_x_offset+ nozzle_length + tail_length;
fuselage_length  = L_total;
fuselage_mid_cut =L_total / 2 -tail_length - nozzle_length; //Plan used to cut the fuselage in two.
rear_fuselage_offset_support = 5;
// --- Derived radius ---
R_front = 1; // nose radius
R_max   = center_width   / 2; // max radius (will be enforced exactly)
R_tail  = 7;//5; // tail radius
ct_part_frame_num       = 100;    // sections numbers (+ = smoother)
fuselage_ellipse_param = [7,4.8]; //Super ellipse fuselage shape parameter [x,y]
fuselage_scale_y_top    = 1.25;  //Parameter use for scaling the fuselage on Y axis top
fuselage_scale_y_bottom = 1;  ///Parameter use for scaling the fuselage on Y axis bottom

//Aeration Parameters
aeration_width = 10;
aeration_length = 20;
x1_aeration = 45;
x2_aeration =3*center_length/4; 
y_aeration = 10;
//Fuselage screws position
fuselage_screw_radius = 1.3;
x1_fuselage_screw = -10;
z1_fuselage_screw = -3;
x2_fuselage_screw = 21;
z2_fuselage_screw = 0;
x3_fuselage_screw = 84;
z3_fuselage_screw = -3;
x4_fuselage_screw = 165;
z4_fuselage_screw = -3;
//Fuselage and center part magnet position
x1_fuselage_magnet = 14;//30;
x2_fuselage_magnet = 156;
magnet_dimension = [5.5,5.5,1.2];
z1_offset_magnet = -7;
z2_offset_magnet = -6;
pitot_radius = 2.4;//2.5;
pitot_length = 15;
//Rear motor screw separation
rear_motor_screw_distance = 14;//11;
rear_motor_y_offset = 4;
//******//


//****************Wing Washout settings**********//
washout_deg = 1.5;         // how many degrees of washout you want 0 for none
washout_start = 60;      // where you would like the washout to start in mm from root
washout_pivot_perc = 25; // Where the washout pivot point is percent from LE
//******//
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

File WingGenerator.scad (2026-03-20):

// ============================================================
//  OpenGeoDrone — Wing Generator
//  RC wing for vase mode FDM printing
// ============================================================
//
//  Tips
//  1 · To embed a part inside the wing, always add a clearance void
//      around it to avoid conflicts with internal ribs
//  2 · If a spar hole disappears: the vase circuit path to the
//      nearest edge is too long → toggle spar_flip_side_X
//  3 · "Normalized tree growing past 200000 elements" → lower wing_sections
//
// ============================================================


// ============================================================
//  AIRFOIL PROFILES
// ============================================================

// Wing airfoils
include <lib/openscad-airfoil/m/mh61.scad>
include <lib/openscad-airfoil/n/naca0008.scad>
af_vec_path_root =             airfoil_MH61_path();
af_vec_path_mid  =             airfoil_MH61_path();
af_vec_path_tip  =             airfoil_MH61_path();
module RootAirfoilPolygon() {  airfoil_MH61();  }
module MidAirfoilPolygon()  {  airfoil_MH61();  }
module TipAirfoilPolygon()  {  airfoil_MH61();  }

//Profil use for winglet => symetric
module wingletAirfoilPolygon() {  airfoil_NACA0008();  }



// ============================================================
//  PART SELECTION
// ============================================================

Left_side      = true;   // generate left half-wing
Right_side     = false;  // generate right half-wing (mirrored)
create_winglet = false;  // attach winglet to tip


// ============================================================
//  RENDER QUALITY
// ============================================================

draft_quality = false;

$fn = $preview ? 0.05 : 80;
$fa = $preview ?  0.1 :  5;   // max angle between segments
$fs = $preview ? 0.05 :  1;   // max segment length (mm)

wing_sections = draft_quality ? 5 : 30;  // spanwise resolution — lower if render is slow


// ============================================================
//  WING PLANFORM
// ============================================================

wing_mm               = 500;  // half-wingspan (mm)
wing_root_chord_mm    = 210;  // root chord (mm)
wing_tip_chord_mm     = 110;  // tip chord — trapezoidal mode only (mm)
wing_center_line_perc = 70;   // reference line position from LE (%)

wing_mode      = 2;    // 1 = trapezoidal   2 = elliptic
elliptic_param = 3.5;  // super-ellipse exponent: 2 = true ellipse, >2 = squarer tip

center_airfoil_change_perc = 100;  // spanwise % where mid airfoil starts  (100 = off)
tip_airfoil_change_perc    = 100;  // spanwise % where tip airfoil starts  (100 = off)
slice_transisions          = 0;    // blend slices between airfoils        (0 = off)


// ============================================================
//  SPAN SECTION LENGTHS   —   must sum to wing_mm
// ============================================================

ellipse_maj_ax = 9;   // motor arm tube semi-axis Z (mm)
ellipse_min_ax = 13;  // motor arm tube semi-axis Y (mm)

motor_arm_width        = 2 * ellipse_maj_ax;  // = 18 mm
motor_arm_to_wing_hull = 10;  // hull blend length between motor arm and wing (mm)

wing_root_mm = 215;  // root section spanwise length (mm)
wing_mid_mm  = 245;  // mid section spanwise length  (mm)
wing_tip_mm  = wing_mm - wing_root_mm - wing_mid_mm - motor_arm_width;  // derived


// ============================================================
//  AERODYNAMIC / GRAVITY CENTER
// ============================================================

AC_CG_margin        = 10;    // CG target: % aft of mean aerodynamic center
aerodyn_center_plot = false; // show aerodynamic center point (debug)
gravity_center_plot = false; // show gravity center point     (debug)


// ============================================================
//  MOTOR ARM  (geometry only — no motor arm printed here)
// ============================================================

motor_arm_length_front       = 170;  // front tube length (mm)
motor_arm_length_back        = 235;  // rear  tube length (mm)
motor_arm_y_offset           = 3;    // Y offset (mm)
motor_arm_height             = 19;   // cross-section height (mm)
motor_arm_tilt_angle         = 20;   // tilt angle (deg)
motor_arm_screw_fit_offset   = 2;    // screw position fine-tune after rotation
motor_arm_grav_center_offset = 35;   // offset from gravity center (mm)
gravity_line_y_offset        = -1;   // Y offset for gravity reference line


// ============================================================
//  CENTER / FUSELAGE DIMENSIONS  (referenced by spar lengths)
// ============================================================

center_width         = 90;   // max fuselage width (mm)
center_length        = 275;  // fuselage total length (mm)
center_height        = 15;   // fuselage height (mm)
center_part_y_offset = 0;
main_stage_y_width   = 2.2 * center_height / 3;
main_stage_x_offset  = center_length / 10;


// ============================================================
//  LEADING EDGE SWEEP  (X shift of LE along span)
// ============================================================

use_custom_lead_edge_sweep = true;

// [ spanwise_z_mm,  x_shift_mm ]
lead_edge_sweep = [
    [0,       0],
    [wing_mm, 281]
];


// ============================================================
//  DIHEDRAL / Y CURVE  (vertical bow of LE along span)
// ============================================================

use_custom_lead_edge_curve = false;
curve_amplitude = 0.10;
max_amplitude   = 400;

// [ spanwise_z_mm,  y_offset_mm ]
lead_edge_curve_y = [
    [wing_mm - wing_tip_mm,       0 * max_amplitude / 10],
    [wing_mm - 9*wing_tip_mm/10,  0 * max_amplitude / 10],
    [wing_mm - 8*wing_tip_mm/10,  0 * max_amplitude / 10],
    [wing_mm - 7*wing_tip_mm/10,  0 * max_amplitude / 10],
    [wing_mm - 6*wing_tip_mm/10,  1 * max_amplitude / 10],
    [wing_mm - 5*wing_tip_mm/10,  2 * max_amplitude / 10],
    [wing_mm - 4*wing_tip_mm/10,  4 * max_amplitude / 10],
    [wing_mm - 3*wing_tip_mm/10,  6 * max_amplitude / 10],
    [wing_mm - 2*wing_tip_mm/10,  8 * max_amplitude / 10],
    [wing_mm - 1*wing_tip_mm/10, 11 * max_amplitude / 10],
    [wing_mm,                    14 * max_amplitude / 10]
];


// ============================================================
//  WASHOUT  (progressive nose-down rotation toward tip)
// ============================================================

washout_deg        = 1.5;  // total washout angle (deg)  — 0 = none
washout_start      = 60;   // spanwise start of washout from root (mm)
washout_pivot_perc = 25;   // pivot point as % of local chord from LE


// ============================================================
//  INTERNAL GRID STRUCTURE
// ============================================================

add_inner_grid   = true;   // must be true when spar_hole = true
grid_mode        = 2;      // 1 = diamond lattice   2 = spar walls + transverse ribs
create_rib_voids = false;  // punch lightening holes in ribs

// Grid mode 1 — diamond lattice
grid_size_factor = 2;  // scales the diamond cell size

// Grid mode 2 — spar walls + ribs
spar_num    = 3;   // number of longitudinal spar walls
spar_offset = 12;  // outermost spar wall offset from LE/TE (mm)
rib_num     = 14;  // number of transverse ribs
rib_offset  = 3;   // rib wall thickness offset (mm)



// ============================================================
//  ELEVONS
// ============================================================

create_aileron = true;

// Skin gap between elevon and wing (tune if elevon binds after printing)
top_y_offset = 1.2;
bot_y_offset = 1.5;

aileron_thickness         = 32;   // elevon depth toward LE (mm)
aileron_pin_hole_diameter = 1.5;  // hinge pin diameter (mm)
aileron_pin_hole_length   = 7;    // hinge pin length (mm)
ailerons_z_end_offset     = 3.5;
aileron_cyl_radius        = 6;    // void cylinder radius at hinge
aileron_reduction         = 0;    // span reduction each side for fit clearance (mm)

y_offset_aileron_to_wing   = 0.6;   // gap between elevon and wing skin
cylindre_wing_dist_nosweep = 1;     // cylinder-to-cube gap for non-swept sections
cylindre_wing_dist_sweep   = -9.5;  // cylinder-to-cube gap for swept sections

// Command pin geometry (servo horn connection)
aileron_command_pin_void_length = 10;
aileron_command_pin_width       = 7.5;
aileron_command_pin_s_radius    = 0.6;
aileron_command_pin_b_radius    = 1.7;
aileron_command_pin_x_offset    = 3;

// Derived — do not edit
aileron_dist_LE_command_center = aileron_thickness
    - aileron_command_pin_width
    - aileron_command_pin_b_radius
    - aileron_command_pin_x_offset;
aileron_dist_LE_pin_center = aileron_thickness;

void_offset_command_ailerons  = 1.3;  // rib clearance void around command pin
void_offset_pin_hole_ailerons = 2.5;  // rib clearance void around hinge pin
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

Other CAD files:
3mf_print_part/X1C_Right_Root_part.3mf
3mf_print_part/X1C_Left_Root_part.3mf
stl_print_part/Left_Servo_horn.stl
3mf_print_part/X1C_Right_Mid_Aileron_part.3mf
stl_print_part/Left_Motor_arm_front.stl
3mf_print_part/H2D_Right_Mid_Aileron_part.3mf
3mf_print_part/H2D_Center_part.3mf
3mf_print_part/H2D_Left_Root_part.3mf
3mf_print_part/H2D_Motor_Arms_and_sides.3mf
3mf_print_part/X1C_Center_part.3mf
3mf_print_part/X1C_Left_Mid_Aileron_part.3mf
stl_print_part/Center_part.stl
stl_print_part/Clamp_fixation_big.stl
stl_print_part/Rear_motor_part.stl
stl_print_part/Right_Motor_arm_back.stl

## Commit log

2025-11-17 Fix bug mid to ailerons connection + wing tip upgrade + wing tip attached
    [Flyhigh.scad]
2025-11-18 Clean motor arm + winglet attach reduction + improve quality
    [Flyhigh.scad]
2025-11-19 modify central part + fuselage generator design
    [Flyhigh.scad]
2025-11-20 servo horn design
    [Flyhigh.scad]
2025-11-21 servo horn logic function implementation + add tool for full wing display
    [Flyhigh.scad]
2025-12-11 Add battery attach + rear motor backward + attach mid to motor arm and winglet
    [Center_part.stl, Flyhigh.scad]
2026-01-07 Add wing root cable passage for motor and servo
    [Center_part.stl, Flyhigh.scad]
2026-01-20 Servo hole update for screw fitting
    [Flyhigh.scad]
2026-01-21 Rear spar orthogo and square section + CG line on motor arm + better tawaki and ESC attach + bigger main stage and grid
    [Flyhigh.scad]
2026-02-03 Change profil to MH61 + Add gravity line on motor arm + winglet improvement + spar adjust and ortho spar 6mm diam
    [Flyhigh.scad]
2026-02-03 clamp to attach part together adding
    [Flyhigh.scad]
2026-02-04 Clamp module added + clamp added to generator stl + winglet to mid attach improv
    [Flyhigh.scad]
2026-02-11 Center part size adaptation to printer + larger + more size for sensitive equipment
    [Flyhigh.scad]
2026-02-17 Arm length change to avoid helix wing overlap + fix bug gravity line stl
    [Flyhigh.scad]
2026-02-17 Main clean
    [Flyhigh.scad]
2026-02-19 Winglet : change dilatation factor PLA + add clamp btw winglet and wing and remove hook attach
    [Flyhigh.scad]
2026-02-24 Add pitch angle on arm center and fuselage + rear motor part implementation + fuselage design
    [Flyhigh.scad]
2026-02-25 Fuselage design + wings hull + rear motor fixed
    [Flyhigh.scad]
2026-02-27 Fuselage design + fix cable passage issue and clamp issue + attach bottom
    [Flyhigh.scad]
2026-02-27 Fuselage design with overlapping fix
    [Flyhigh.scad]
2026-03-02 Fuselage rear block + overlap + magnet fuselage + pitot + hole rear motor cable + tawaki and ESC inversion
    [Flyhigh.scad]
2026-03-03 Fix the logic to make the stl generator works with new part
    [Flyhigh.scad]
2026-03-04 Decrease height tawaki + remove ESC ext fixation + fix issue longerons + change aeration on sides + clean fuselage sides + change ctpart grid + screw fuselage issue
    [Flyhigh.scad]
2026-03-06 Magnet fix + Rear ct grid + front transition fix + pitot fix + battery room in upper fuselage
    [Flyhigh.scad]
2026-03-13 Fuselage shape work for C1 design
    [Flyhigh.scad]
2026-03-13 Center part and design modification to new iteration
    [Flyhigh.scad]
2026-03-19 Update Readme + Add fuselage top and down asymetrie + correction on magnet support
    [OpenGeoDrone.scad]
2026-03-19 Change name of main file to OpenGeoDrone
    [Flyhigh.scad, OpenGeoDrone.scad]
2026-03-20 Update Readme and start a wingGenerator file for demo
    [WingGenerator.scad]
2026-03-24 add stl part to folder
    [Clamp_fixation_big.stl, Clamp_fixation_small.stl, Left_Servo_horn.stl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]
2026-04-15 Center part screw modif + rear motor part update + pitot diameter change + add battery holder and cable mgnt + fuselage top increase
    [Left_Servo_horn.stl, OpenGeoDrone.scad, Rear_motor_part.stl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]
2026-04-24 Update readme + add Bambulab preset H2D & X1C for Vase print
2026-05-05 Change inside structure and readme
    [OpenGeoDrone.scad]
2026-05-06 Change inside structure + change winglet + bug preview fixed + TE LE inner structure issue fixed
    [OpenGeoDrone.scad]
2026-05-18 Update readme + Add 3mf files + update stl files
    [Center_part.stl, Clamp_fixation_big.stl, Clamp_fixation_small.stl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]
2026-09-11 Design optimization to reduce mass
    [OpenGeoDrone.scad]
